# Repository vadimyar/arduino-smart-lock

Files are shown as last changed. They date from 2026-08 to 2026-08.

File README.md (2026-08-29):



# 🚪 Умный дверной замок на Arduino Nano

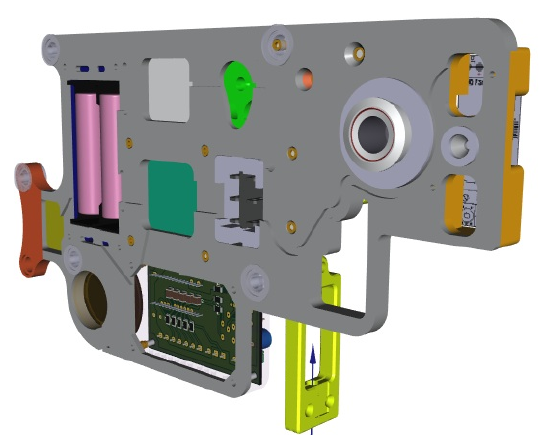
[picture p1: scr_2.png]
Проект умного замка


**Автономная система управления дверным замком с психоакустической индикацией и интеллектуальным контролем доступа**

Проект разработан с упором на надежность, использование свободного ПО (Linux, Arduino IDE) и комфорт пользователей.

---

## ✨ Особенности проекта

### 🔇 Психоакустический "тихий режим"
Вместо стандартного пронзительного писка используется алгоритм **сверхкоротких импульсов** (микросекундные задержки), превращающий звук активного зуммера в мягкий, интеллигентный "щелчок" (в стиле счетчика Гейгера из Half-Life).

### 🎵 Динамическая мелодия удержания
При удержании двери в открытом состоянии система подает сигналы с **ускоряющимся ритмом**. Интервалы между сигналами рассчитываются по формуле **геометрической прогрессии** (закон Вебера-Фехнера), что интуитивно воспринимается человеком как нарастающее "предупреждение о скором закрытии".

###  Двухуровневая система тревоги
Если замок двери остается разблокированным слишком долго:
1. Включается **звуковая сирена** и мигание светодиода
2. Через заданное время **звук автоматически отключается** (чтобы не беспокоить)
3. **Визуальная LED-индикация** продолжает работать до момента блокирования замка двери

### ⚙️ Настраиваемая громкость
3 уровня громкости "щелчков", выбираемые через сервисную кнопку и сохраняемые в EEPROM.

### 🛡️ Аппаратная надежность
- Использование **watchdog-таймера (WDT)**
- Защита от дребезга контактов (debounce)
- Корректное управление питанием сервопривода (отключение после движения)

---

## 🔧 Используемые компоненты

| Компонент | Назначение |
|---|---|
| **Arduino Nano** (ATmega328P) | Микроконтроллер |
| **Сервопривод** (SG90/MG995) | Механическое открытие/закрытие |
| **Датчик Холла** | Определение положения ригеля |
| **Сканер отпечатков пальцев** (К202+R503) | Контроль доступа |
| **Wi-Fi модуль** | Управление замком из УД с Алисой |
| **Активный зуммер** | Звуковая индикация |
| **LED индикаторы** | Визуальная индикация состояния |
| **Кнопки/сканеры** | Триггеры открытия (активный низкий уровень) |

---

## 📐 Схема подключения

| Компонент | Пин Arduino | Примечание |
|---|---|---|
| Сервопривод | D10 | PWM |
| Зуммер | D9 | PWM (режим быстрых импульсов) |
| Датчик Холла | D6 | INPUT_PULLUP, активный низкий |
| Сервисная кнопка | D4 | INPUT_PULLUP, настройка громкости |
| Триггеры открытия | D2, D3, D5 | INPUT_PULLUP |
| LED индикации | D8, D11, D13 | D11 - PWM (режим "дыхание" подсветки) |

---

## 🚀 Установка и настройка

### 1. Прошивка
Загрузите код `door_lock.ino` с помощью **Arduino IDE** или **PlatformIO**.

### 2. Настройка громкости
- **Удерживайте** сервисную кнопку (D4) более **1.5 секунды** → вход в режим настройки
- **Коротко нажимайте** кнопку для переключения между 3 уровнями громкости
- **Удерживайте** кнопку 1.5 секунды → сохранение в EEPROM и выход

### 3. Основные параметры
В начале файла `door_lock.ino` можно изменить:

```cpp
const unsigned long HOLD_TIME = 10000;        // Время удержания (мс)
const byte HOLD_TICK_COUNT = 30;              // Количество тиков
const unsigned long ALARM_DELAY = 15000;      // Задержка до тревоги (мс)
const unsigned long ALARM_SOUND_DURATION = 15000; // Длительность звука тревоги (мс)

```

### 🤝 Вклад в проект
Проект создан с любовью к свободному ПО и точным наукам. Если у вас есть идеи по улучшению кода, оптимизации или новые идеи для мелодий — Pull Request'ы приветствуются!

### 📜 Лицензия
Этот проект распространяется под лицензией MIT License — используйте freely в любых целях.

### 👨‍💻 Автор
**Vadimyar** — физик, энтузиаст Linux и свободного ПО, разработчик образовательных проектов на Arduino/ESP.

> *"Замок должен быть не только надежным, но и интеллигентным"*

<br>

<div align="center">

Сделано с ❤️ на Arduino и Linux
[⬆️ В начало](#top)

</div>

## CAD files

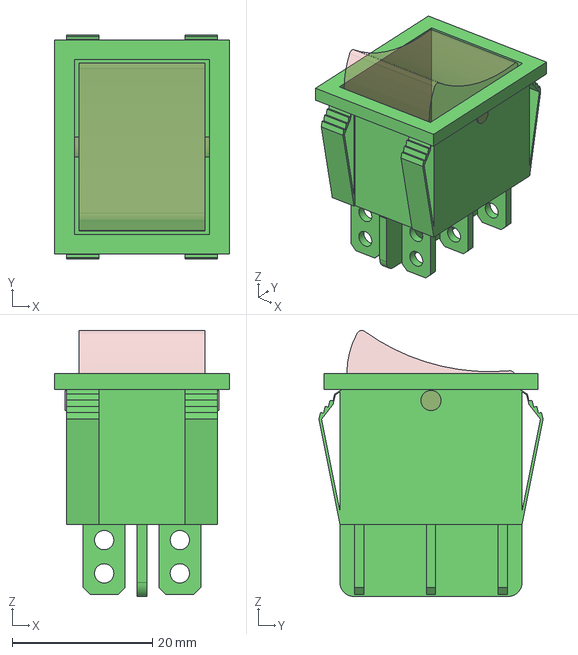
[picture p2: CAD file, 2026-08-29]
KiCAD/door/Compressor_001-Сеть_тумблерСеть_тумблер_клавиша.step
25.0 x 32.0 x 38.0 mm
Сеть_тумблер_клавиша
Сеть_тумблер_корпус

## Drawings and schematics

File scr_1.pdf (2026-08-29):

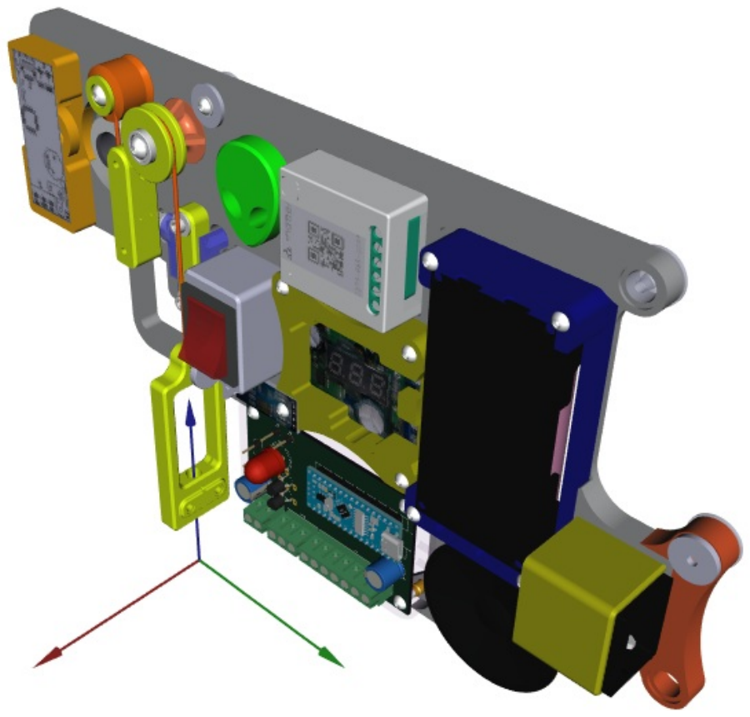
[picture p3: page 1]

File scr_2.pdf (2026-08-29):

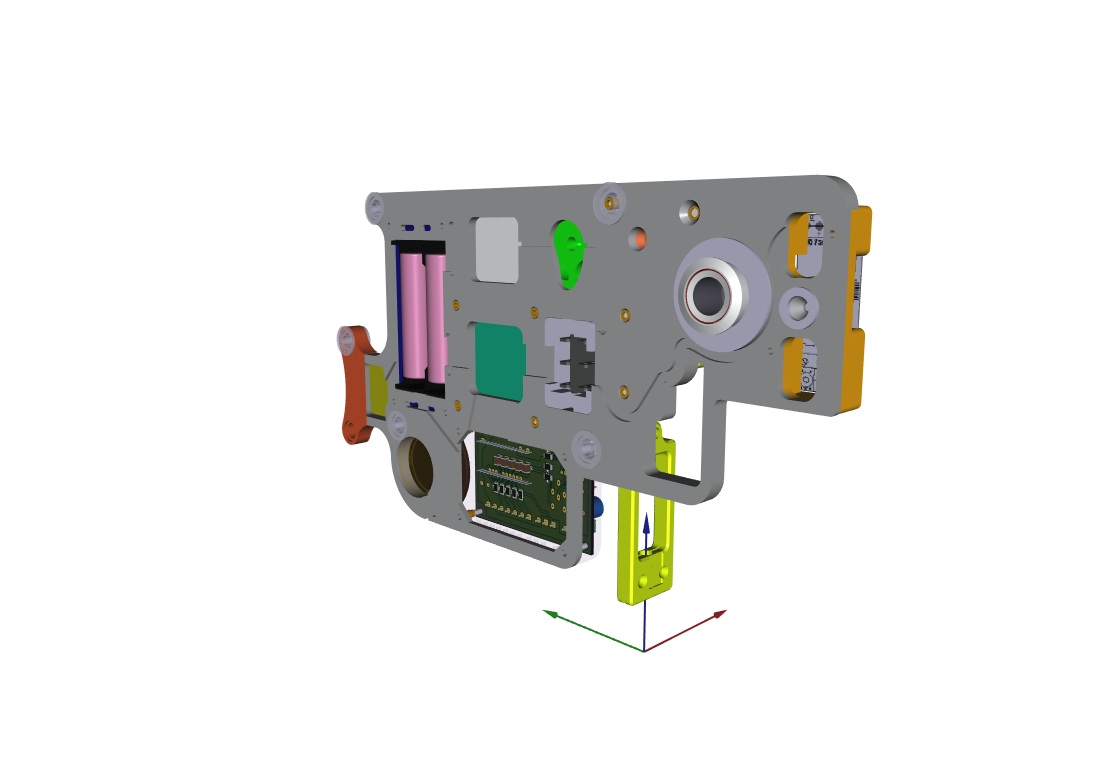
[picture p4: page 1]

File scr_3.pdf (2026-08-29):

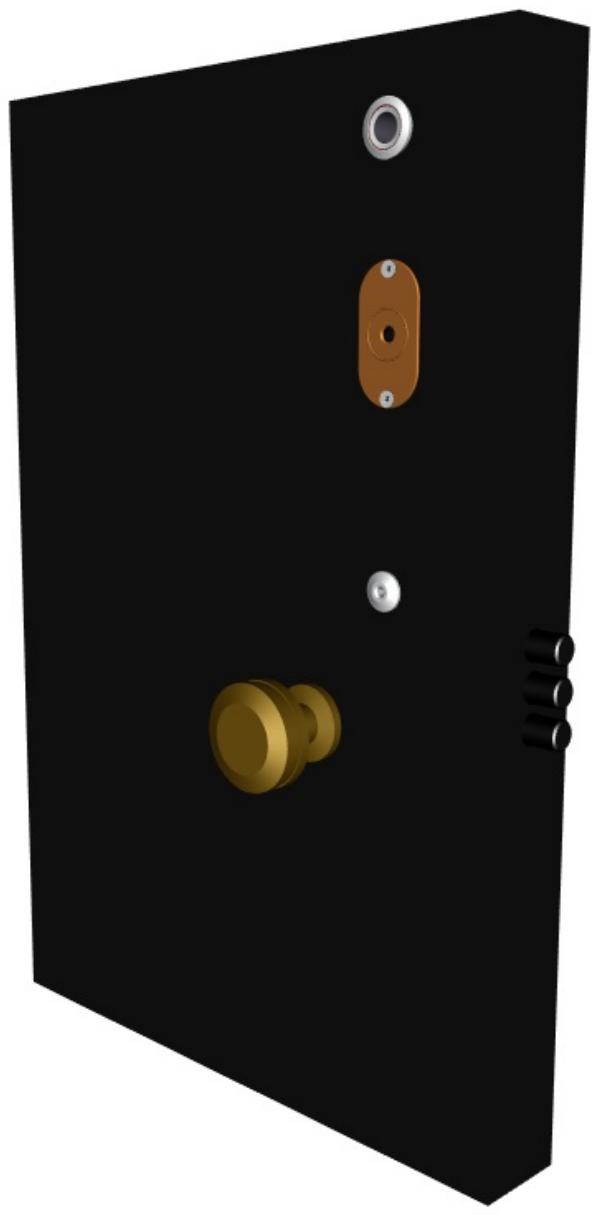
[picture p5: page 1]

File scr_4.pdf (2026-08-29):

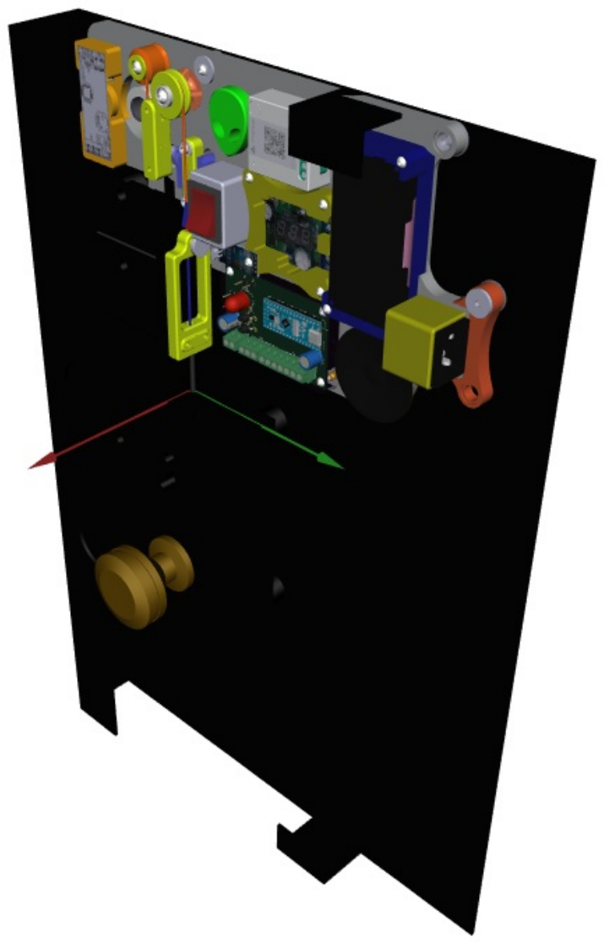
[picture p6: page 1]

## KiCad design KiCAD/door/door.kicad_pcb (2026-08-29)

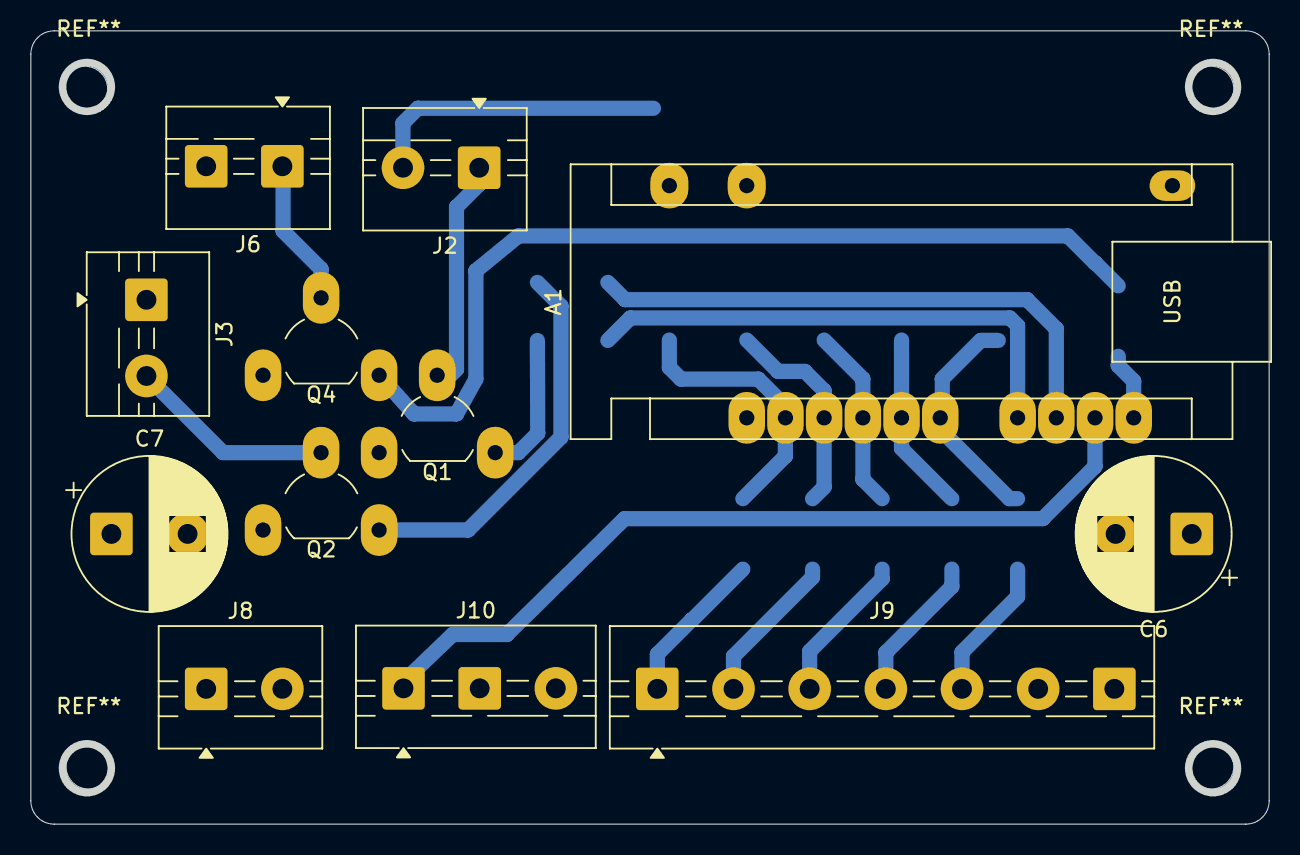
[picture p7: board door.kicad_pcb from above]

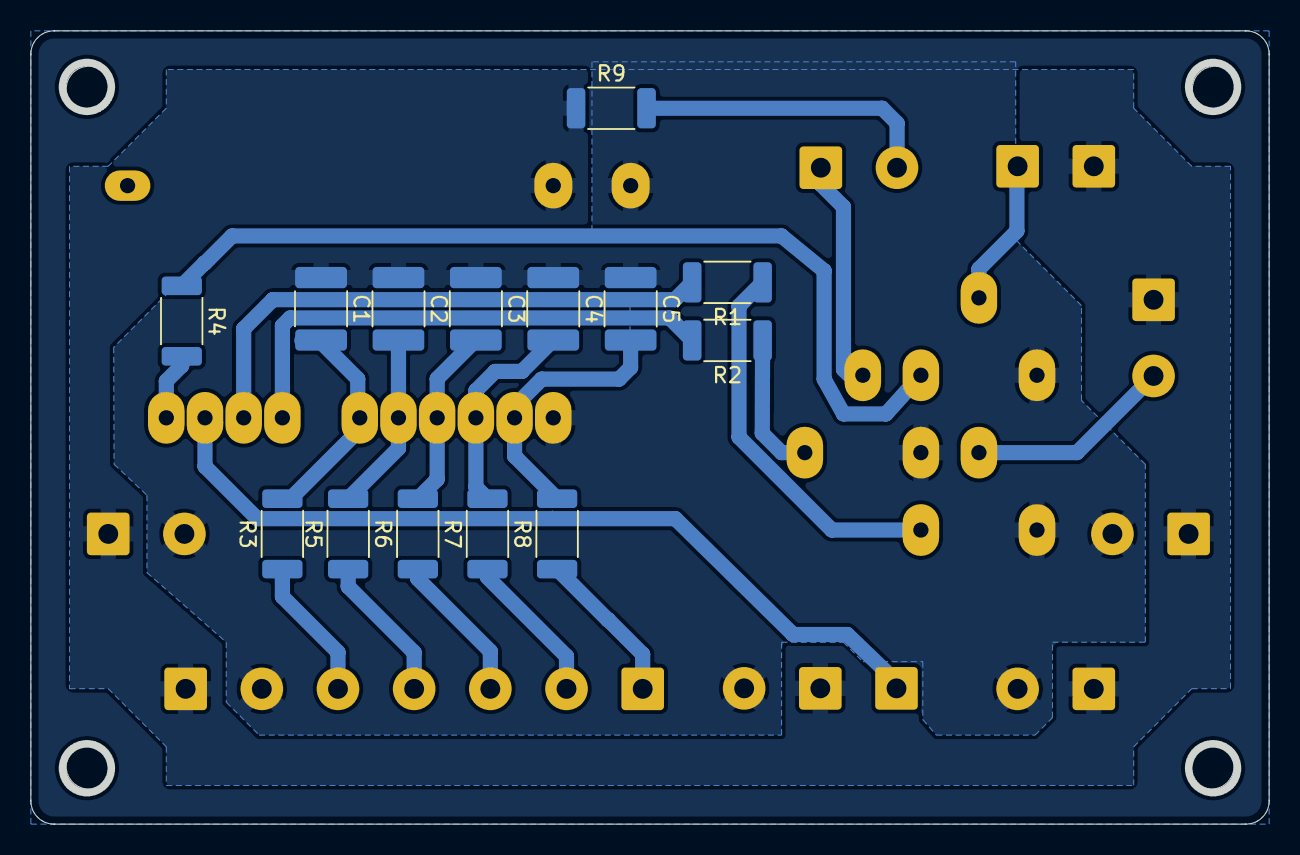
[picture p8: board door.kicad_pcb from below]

Board: 2 copper layers, 81.3 x 52.1 mm, 26 parts (14 on the bottom side), 23 nets.

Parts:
A1: Arduino_Nano_v3.x; Arduino_Nano
C1, C2, C3, C4, C5: 100nf; C_1812_4532Metric
C6, C7: 1.5mf; CP_Radial_D10.0mm_P5.00mm
J2, J3, J6, J8: Screw_Terminal_01x02; TerminalBlock_MaiXu_MX126-5.0-02P_1x02_P5.00mm
J9: Screw_Terminal_01x04; TerminalBlock_MaiXu_MX126-5.0-07P_1x07_P5.00mm
J10: Screw_Terminal_01x03; TerminalBlock_MaiXu_MX126-5.0-03P_1x03_P5.00mm
Q1, Q2, Q4: PN2222A; TO-92_SuperWide
R1, R2, R3, R4, R5, R6, R7, R8: 1k; R_2010_5025Metric
R9: 270; R_2010_5025Metric

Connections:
+5V: A1.27 (+5V), C6.1, C7.1, J3.1, J6.2, J8.1, J9.7, J10.2, R9.1
GND: A1.4 (GND), A1.29 (GND), C1.1, C2.1, C3.1, C4.1, C5.1, C6.2, C7.2, J8.2, J9.6, J10.3, Q1.1 (E), Q2.1 (E), Q4.1 (E)
unnamed: A1.5 (D2), C5.2, R8.2
unnamed: A1.6 (D3), C4.2, R7.2
unnamed: A1.7 (D4), C3.2, R6.2
unnamed: A1.8 (D5), C2.2, R5.2
unnamed: A1.9 (D6), C1.2, R3.2
unnamed: A1.11 (D8), R2.2
unnamed: A1.12 (D9), R1.2
unnamed: A1.13 (D10), J10.1
unnamed: A1.14 (D11), R4.2
unnamed: J2.1, Q1.2 (C)
unnamed: J2.2, R9.2
unnamed: J3.2, Q2.2 (C)
unnamed: J6.1, Q4.2 (C)
unnamed: J9.1, R8.1
unnamed: J9.2, R7.1
unnamed: J9.3, R6.1
unnamed: J9.4, R5.1
unnamed: J9.5, R3.1
unnamed: Q1.3 (B), R2.1
unnamed: Q2.3 (B), R1.1
unnamed: Q4.3 (B), R4.1

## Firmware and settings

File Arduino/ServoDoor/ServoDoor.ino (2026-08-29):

#include <Servo.h>
#include <avr/wdt.h>
#include <EEPROM.h>

// ==========================================
// 1. ОБЪЯВЛЕНИЕ ПИНОВ И КОНСТАНТ
// ==========================================

// --- Пины выхода ---
const byte SERVO_PIN = 10;         // Собственно сервопривод
const byte LED_PIN = 8;            // Индикатор состояния
const byte BUZZER_PIN = 9;         // Активная пикалка
const byte STATUS_LED_PIN = 13;    // тупо мигает когда комият собаку
const byte BREATHING_LED_PIN = 11; // дыхание подсветки главной кнопки

// --- Пины входов ---
const byte TRIG_PINS[] = {2, 3, 4, 5};  // пины входов с датчиков активный низкий уровень
const byte NUM_TRIGS = sizeof(TRIG_PINS) / sizeof(TRIG_PINS[0]); // назначение пинов
const byte SENSOR_LATCH_PIN = 6;        // вход сигнал с датчика Холла (открыто/закрыто)

const byte CONFIG_BUTTON_INDEX = 2;     // для D4 и меню по кнопке настройки 

// --- Механика и скорость ---
const int ANGLE_DOWN = 160;      // начальный угол сервы больше 160 нельзя, упремся!
const int ANGLE_UP = 105;        // конечный угол сервы меньше 40 нельзя, угол раскрытия макс: 160 - 40 = 120 это 55 мм хода тросика!
const int MOVE_DELAY = 7;        // скважность импульсов сервы от этого зависит его скорость

// --- Звуки и время ---        
const unsigned long HOLD_TIME = 10000;   // ⚠️ МЕНЯЙ ТОЛЬКО ЗДЕСЬ - паузы пересчитаются автоматически!
const byte HOLD_TICK_COUNT = 30;         // Количество тиков в мелодии удержания
const unsigned long DEBOUNCE_TIMEOUTS[] = { 3000, 3000, 3000, 3000 }; 
const unsigned long ALARM_DELAY = 15000; // Время до НАЧАЛА тревоги

// ⚠️ НОВОЕ: Максимальная продолжительность ЗВУКА тревоги (мс)
// После этого времени звук выключится, но LED продолжит мигать, пока дверь открыта.
const unsigned long ALARM_SOUND_DURATION = 15000; // 15 секунд звучания

const unsigned long LONG_PRESS_DURATION = 1500; 
const int EEPROM_VOLUME_INDEX = 0; 

// ==========================================
// 🔇 НАСТРОЙКИ "ТИХОГО РЕЖИМА" ЗУММЕРА
// ==========================================
#define USE_SAFE_PULSE_MODE 

const unsigned int VOLUME_LEVELS[] = {100, 10000, 100000}; // значения для меню выбора громкости пищалки
const byte MAX_VOLUME_LEVELS = sizeof(VOLUME_LEVELS) / sizeof(VOLUME_LEVELS[0]); //сюда сохраняем выбранный уровеньгромкости

byte currentVolumeIndex = 0;

// ==========================================
// 🎵 МЕЛОДИИ (Партитуры) 🎵
// ==========================================

const unsigned int MELODY_OPEN[] = {50, 50, 0}; // "." один короткий тик и короткая пауза

const unsigned int MELODY_CLOSE[] = {50, 50, 0}; // {300, 102, 300, 102, 300, 503, 0}; // "_ _ _" три длинных тика

const unsigned int MORSE_AR[] = {100, 102, 300, 102, 100, 102, 300, 102, 100, 503, 0};  // "._._." ти-таа-ти-таа-ти

const unsigned int MELODY_ALARM[] = {100, 102, 100, 102, 100, 303, 300, 102, 300, 102, 300, 303, 100, 102, 100, 102, 100, 603, 0};  // "... _ _ _ ..." ну ты понял

// ==========================================
// 🎼 ДИНАМИЧЕСКАЯ МЕЛОДИЯ УДЕРЖАНИЯ
// ==========================================
// Массивы рассчитываются автоматически при старте на основе HOLD_TIME
unsigned int holdMelodyBuffer[HOLD_TICK_COUNT * 2 + 1];

// Функция расчета ускоряющихся пауз (геометрическая прогрессия)
void calculateHoldMelody() {
  const float q = 0.9;
  const unsigned int MIN_PAUSE_MS = 10; // Минимальная пауза между тиками
  const unsigned int TICK_DURATION_MS = 1; // Минимальная длительность (реальная определяется в setBuzzerOn)
  
  float a1 = (float)HOLD_TIME * (1.0 - q) / (1.0 - pow(q, HOLD_TICK_COUNT));
  
  for (byte i = 0; i < HOLD_TICK_COUNT; i++) {
    holdMelodyBuffer[i * 2] = TICK_DURATION_MS; // 1 мс (минимум, реальная длительность из VOLUME_LEVELS)
    
    unsigned int calculatedPause = (unsigned int)(a1 * pow(q, i));
    holdMelodyBuffer[i * 2 + 1] = (calculatedPause < MIN_PAUSE_MS) ? MIN_PAUSE_MS : calculatedPause;
  }
  holdMelodyBuffer[HOLD_TICK_COUNT * 2] = 0;
  
  Serial.print(F("Мелодия удержания рассчитана: "));
  Serial.print(HOLD_TICK_COUNT);
  Serial.print(F(" тиков за "));
  Serial.print(HOLD_TIME);
  Serial.println(F(" мс"));
}

// --- Дыхание подсветки ---
const unsigned long BREATH_PERIOD_MS = 2000; 
const byte MIN_BRIGHTNESS = 5;  
const byte MAX_BRIGHTNESS = 255; 

// ==========================================
// 2. ДВИЖОК ВОСПРОИЗВЕДЕНИЯ МЕЛОДИЙ
// ==========================================
const unsigned int* playingMelody = nullptr;
int melodyIndex = 0;
unsigned long melodyStepStart = 0;
bool isMelodyPlaying = false;
bool loopCurrentMelody = false;
bool isHoldMelodyStarted = false; 

void setBuzzerOn() {
  #ifdef USE_SAFE_PULSE_MODE
    digitalWrite(BUZZER_PIN, HIGH);
    delayMicroseconds(VOLUME_LEVELS[currentVolumeIndex]); 
    digitalWrite(BUZZER_PIN, LOW);
  #else
    analogWrite(BUZZER_PIN, 255);
  #endif
}

void setBuzzerOff() {
  analogWrite(BUZZER_PIN, 0);
  digitalWrite(BUZZER_PIN, LOW);
}

void playMelody(const unsigned int* melody, bool loop = false) {
  playingMelody = melody;
  melodyIndex = 0;
  melodyStepStart = millis();
  isMelodyPlaying = true;
  loopCurrentMelody = loop;
  if (playingMelody[0] > 0) setBuzzerOn();
}

void stopMelody() {
  isMelodyPlaying = false;
  playingMelody = nullptr;
  setBuzzerOff();
}

void updateMelody(unsigned long currentTime) {
  if (!isMelodyPlaying || playingMelody == nullptr) return;
  unsigned int duration = playingMelody[melodyIndex];
  
  if (duration == 0) {
    if (loopCurrentMelody) {
      melodyIndex = 0; duration = playingMelody[0]; melodyStepStart = currentTime;
      setBuzzerOn();
    } else {
      isMelodyPlaying = false; playingMelody = nullptr; setBuzzerOff();
    }
    return;
  }

  if (currentTime - melodyStepStart >= duration) {
    melodyStepStart = currentTime;
    melodyIndex++;
    if (playingMelody[melodyIndex] == 0) {
      if (loopCurrentMelody) { 
        melodyIndex = 0; 
        setBuzzerOn(); 
      } else { 
        isMelodyPlaying = false; playingMelody = nullptr; setBuzzerOff(); 
      }
    } else {
      if (melodyIndex % 2 == 0) {
        setBuzzerOn();
      } else {
        setBuzzerOff();
      }
    }
  }
}

// ==========================================
// 3. КОНЕЧНЫЙ АВТОМАТ И ПЕРЕМЕННЫЕ
// ==========================================
enum SystemState {
  STATE_IDLE,           
  STATE_MOVING_UP,      
  STATE_HOLDING,        
  STATE_MOVING_DOWN,
  STATE_CONFIG          
};

SystemState currentState = STATE_IDLE;
unsigned long stateStartTime = 0;
int currentAngle = ANGLE_DOWN;
int targetAngle = ANGLE_DOWN;
unsigned long lastStepTime = 0; 

unsigned long lastLedToggleTime = 0;
bool ledState = false;

unsigned long latchOpenTime = 0;      
bool isAlarming = false;              
unsigned long alarmSoundStartTime = 0; // ⚠️ НОВОЕ: Время начала звука тревоги

bool lastState[NUM_TRIGS];
unsigned long lastTriggerTime[NUM_TRIGS];

unsigned long configButtonPressTime = 0;
bool configButtonIsPressed = false;
bool configLongPressHandled = false; 

Servo doorLock;

// ==========================================
// 4. ФУНКЦИЯ НАСТРОЙКИ
// ==========================================
void setup() {
  Serial.begin(115200);
  wdt_enable(WDTO_2S); 
  
  for (byte i = 0; i < NUM_TRIGS; i++) {
    pinMode(TRIG_PINS[i], INPUT_PULLUP);
    lastState[i] = HIGH;
    lastTriggerTime[i] = 0;
  }
  
  pinMode(LED_PIN, OUTPUT);
  pinMode(BUZZER_PIN, OUTPUT);
  pinMode(STATUS_LED_PIN, OUTPUT);
  pinMode(BREATHING_LED_PIN, OUTPUT); 
  pinMode(SENSOR_LATCH_PIN, INPUT_PULLUP);

  setBuzzerOff();

  doorLock.attach(SERVO_PIN);
  doorLock.write(ANGLE_DOWN);
  
  unsigned long setupStart = millis();
  while (millis() - setupStart < 500) { wdt_reset(); }
  
  doorLock.detach();
  digitalWrite(LED_PIN, LOW);
  
  // --- ЧТЕНИЕ УРОВНЯ ГРОМКОСТИ ИЗ EEPROM ---
  byte savedVolume = EEPROM.read(EEPROM_VOLUME_INDEX);
  if (savedVolume < MAX_VOLUME_LEVELS) {
    currentVolumeIndex = savedVolume;
    Serial.print(F("Загружен уровень громкости из EEPROM: ")); 
    Serial.println(currentVolumeIndex + 1);
  } else {
    currentVolumeIndex = 0;
    EEPROM.update(EEPROM_VOLUME_INDEX, currentVolumeIndex);
    Serial.println(F("EEPROM пуст. Установлен уровень громкости 1 по умолчанию."));
  }
  
  // --- РАСЧЕТ ДИНАМИЧЕСКОЙ МЕЛОДИИ УДЕРЖАНИЯ ---
  calculateHoldMelody();
  
  Serial.println(F("Система готова. Замок заблокирован."));
}

// ==========================================
// 5. ОСНОВНОЙ ЦИКЛ
// ==========================================
void loop() {
  unsigned long currentTime = millis();
  wdt_reset(); 

  updateMelody(currentTime);

  // --- ОБРАБОТКА СЕРВИСНОЙ КНОПКИ (D4) ---
  bool configBtnState = digitalRead(TRIG_PINS[CONFIG_BUTTON_INDEX]);
  
  if (configBtnState == LOW && lastState[CONFIG_BUTTON_INDEX] == HIGH) {
    configButtonPressTime = currentTime;
    configButtonIsPressed = true;
    configLongPressHandled = false; 
  }
  
  if (configBtnState == HIGH && lastState[CONFIG_BUTTON_INDEX] == LOW) {
    if (configButtonIsPressed) {
      unsigned long pressDuration = currentTime - configButtonPressTime;
      
      if (!configLongPressHandled && pressDuration < LONG_PRESS_DURATION) {
        if (currentState == STATE_CONFIG) {
          currentVolumeIndex++;
          if (currentVolumeIndex >= MAX_VOLUME_LEVELS) currentVolumeIndex = 0;
          
          setBuzzerOn();
          digitalWrite(LED_PIN, HIGH);
          delay(100);
          setBuzzerOff();
          digitalWrite(LED_PIN, LOW);
          
          Serial.print(F("Уровень громкости: ")); Serial.println(currentVolumeIndex + 1);
        } else if (currentState == STATE_IDLE) {
          Serial.println(F("Сервисная кнопка (короткое нажатие в обычном режиме)."));
        }
      }
      configButtonIsPressed = false;
    }
  }
  
  if (configButtonIsPressed && !configLongPressHandled) {
    if ((currentTime - configButtonPressTime) >= LONG_PRESS_DURATION) {
      configLongPressHandled = true; 
      
      if (currentState == STATE_CONFIG) {
        currentState = STATE_IDLE;
        EEPROM.update(EEPROM_VOLUME_INDEX, currentVolumeIndex);
        playMelody(MORSE_AR, false); 
        Serial.print(F("Настройка завершена. Сохранен уровень громкости: "));
        Serial.println(currentVolumeIndex + 1);
      } else if (currentState == STATE_IDLE) {
        currentState = STATE_CONFIG;
        Serial.println(F("Вход в режим настройки громкости зуммера."));
        Serial.print(F("Текущий уровень: ")); Serial.println(currentVolumeIndex + 1);
      }
    }
  }
  lastState[CONFIG_BUTTON_INDEX] = configBtnState;

  // --- ОБРАБОТКА ОСТАЛЬНЫХ КНОПОК (D2, D3, D5) ---
  for (byte i = 0; i < NUM_TRIGS; i++) {
    if (i == CONFIG_BUTTON_INDEX) continue;
    
    bool currentStatePin = digitalRead(TRIG_PINS[i]);
    if (lastState[i] == HIGH && currentStatePin == LOW) {
      if (currentTime - lastTriggerTime[i] >= DEBOUNCE_TIMEOUTS[i]) {
        lastTriggerTime[i] = currentTime;
        lastState[i] = currentStatePin;
        if (currentState == STATE_IDLE) {
          Serial.print(F("Сработал источник на пине ")); Serial.println(TRIG_PINS[i]);
          startUnlockCycle(currentTime);
        }
      }
    }
    lastState[i] = currentStatePin;
  }

  // ==========================================
  // ⚠️ НОВОЕ: ЛОГИКА КОНТРОЛЯ ПОЛОЖЕНИЯ СОБАЧКИ С ТАЙМАУТОМ ЗВУКА
  // ==========================================
  bool latchIsUp = (digitalRead(SENSOR_LATCH_PIN) == LOW);
  
  if (latchIsUp) {
    if (latchOpenTime == 0) latchOpenTime = currentTime;
    
    // 1. Запуск тревоги (звук + начало отсчета времени звука)
    if ((currentTime - latchOpenTime >= ALARM_DELAY) && !isAlarming) {
      isAlarming = true;
      alarmSoundStartTime = currentTime;
      playMelody(MELODY_ALARM, true);
      Serial.println(F("ВНИМАНИЕ: Замок открыт слишком долго! Включена тревога."));
    }
    
    // 2. Принудительная остановка ЗВУКА по истечении ALARM_SOUND_DURATION
    // Флаг isAlarming при этом остается true, чтобы продолжало мигать LED
    if (isAlarming && (currentTime - alarmSoundStartTime >= ALARM_SOUND_DURATION)) {
      if (isMelodyPlaying) {
        stopMelody();
        Serial.println(F("Звук тревоги выключен по таймауту. Дверь всё ещё открыта!"));
      }
    }
  } else {
    // Датчик Холла в покое (дверь закрыта)
    latchOpenTime = 0;
    alarmSoundStartTime = 0;
    if (currentState == STATE_IDLE) {
      if (isAlarming) {
        stopMelody(); // На всякий случай гарантируем остановку
        isAlarming = false;
        digitalWrite(LED_PIN, LOW);
        Serial.println(F("Дверь закрыта. Тревога снята."));
      }
    }
  }

  // 3. Управление миганием LED во время тревоги (работает независимо от звука!)
  if (isAlarming) {
    if (currentTime - lastLedToggleTime >= 300) { // Мигание каждые 300 мс
      lastLedToggleTime = currentTime;
      ledState = !ledState;
      digitalWrite(LED_PIN, ledState ? HIGH : LOW);
    }
  } else if (currentState == STATE_IDLE) {
    // Если не тревога и мы в простое, гасим LED (на случай, если он остался висеть)
    digitalWrite(LED_PIN, LOW);
  }
  // ==========================================

  // --- ИНДИКАЦИЯ LED (Дыхание или Быстрое мигание в конфиге) ---
  if (currentState == STATE_CONFIG) {
    if (currentTime - lastLedToggleTime >= 100) {
      lastLedToggleTime = currentTime;
      ledState = !ledState;
      analogWrite(BREATHING_LED_PIN, ledState ? MAX_BRIGHTNESS : MIN_BRIGHTNESS);
    }
  } else if (!isAlarming) { // Дыхание работает только если нет тревоги
    unsigned long timeInPeriod = currentTime % BREATH_PERIOD_MS;
    float phase = (timeInPeriod * 2.0 * PI) / BREATH_PERIOD_MS;
    int offset = (MAX_BRIGHTNESS + MIN_BRIGHTNESS) / 2;
    int amplitude = (MAX_BRIGHTNESS - MIN_BRIGHTNESS) / 2;
    int currentBrightness = offset + (amplitude * sin(phase));
    analogWrite(BREATHING_LED_PIN, currentBrightness);
  }

  // --- МИГАНИЕ СТАТУСНОГО LED (D13) ---
  static unsigned long d13Timer = 0;
  static bool d13State = false;
  if (currentTime - d13Timer >= 150) {
    d13Timer = currentTime;
    d13State = !d13State;
    digitalWrite(STATUS_LED_PIN, d13State);
  }

  // --- ОБРАБОТКА СОСТОЯНИЙ АВТОМАТА ---
  switch (currentState) {
    case STATE_IDLE:
      break;
    case STATE_MOVING_UP:
      handleMovingUpState(currentTime);
      break;
    case STATE_HOLDING:
      handleHoldingState(currentTime);
      break;
    case STATE_MOVING_DOWN:
      handleMovingDownState(currentTime);
      break;
    case STATE_CONFIG:
      break;
  }
}

// ==========================================
// 6. ФУНКЦИИ ОБРАБОТКИ СОСТОЯНИЙ
// ==========================================

void handleMovingUpState(unsigned long currentTime) {
  if (currentTime - lastStepTime >= MOVE_DELAY) {
    lastStepTime = currentTime;
    if (currentAngle != targetAngle) {
      if (currentAngle < targetAngle) currentAngle++;
      else currentAngle--;
      doorLock.write(currentAngle);
    } else {
      currentState = STATE_HOLDING;
      stateStartTime = currentTime;
      digitalWrite(LED_PIN, HIGH); 
      playMelody(MELODY_OPEN, false);
      isHoldMelodyStarted = false; 
    }
  }
}

void handleHoldingState(unsigned long currentTime) {
  if (!isMelodyPlaying && !isHoldMelodyStarted) {
    playMelody(holdMelodyBuffer, true); // ⚠️ Используем динамический массив!
    isHoldMelodyStarted = true;
  }

  if ((currentTime - stateStartTime) >= HOLD_TIME) {
    currentState = STATE_MOVING_DOWN;
    targetAngle = ANGLE_DOWN;
    lastStepTime = currentTime;
    stopMelody(); 
    isHoldMelodyStarted = false; 
  }
}

void handleMovingDownState(unsigned long currentTime) {
  if (currentTime - lastStepTime >= MOVE_DELAY) {
    lastStepTime = currentTime;
    if (currentAngle != targetAngle) {
      if (currentAngle < targetAngle) currentAngle++;
      else currentAngle--;
      doorLock.write(currentAngle);
    } else {
      finishUnlockCycle();
    }
  }
}

// ==========================================
// 7. ВСПОМОГАТЕЛЬНЫЕ ФУНКЦИИ
// ==========================================

void startUnlockCycle(unsigned long currentTime) {
  currentState = STATE_MOVING_UP;
  stateStartTime = currentTime;
  targetAngle = ANGLE_UP;
  lastStepTime = currentTime;
  digitalWrite(LED_PIN, HIGH); 
  doorLock.attach(SERVO_PIN);
}

void finishUnlockCycle() {
  doorLock.detach();
  currentState = STATE_IDLE;
  digitalWrite(LED_PIN, LOW); 
  playMelody(MELODY_CLOSE, false);
  Serial.println(F("Замок заблокирован."));
}

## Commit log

2026-08-29 Add all project files
    [Compressor_001-Сеть_тумблерСеть_тумблер_клавиша.step, door.dsn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]
2026-08-29 docs: add comprehensive README with features, wiring and setup guide
